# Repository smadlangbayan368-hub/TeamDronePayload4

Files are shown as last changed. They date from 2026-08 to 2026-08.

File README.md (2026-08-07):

# Team 4's Solution to Classroom Challenge Project <'Drone Payload Capacity and Structural Design Analysis Problem'>
This project challenges a team into applying core concepts of physics and engineering to the real-world problem of maximizing the payload capacity of a quadcopter. At the end of this project the team will have practiced designing drone arms and 3D modeling them, programing with MATLAB, and propose a final drone arm design through quantitative and cost analysis.  
  
Please refer to 'DroneDesign_StudentProjectTemplate_Preview.pdf' located in the Documentations folder and [Link](https://github.com/mathworks/MATLAB-Simulink-Challenge-Project-Hub/tree/main/Classroom%20Challenge%20Projects/Projects/Drone%20Payload%20Capacity%20and%20Structural%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) for more specifics about assumptions and requirements.

# Objective
Design at least 2 drone arms with the following criteria:
-  0.5 Kg payload at minimum
-  2:1 thrust-to-weight ratio (TWR) at minimum
-  Factor safety of at least 1.5

 Produce a final report from the results that were gathered for the drone arms  
  -  Including a final design recommendation with justification from analysis of results.   

Bonus Goal (Personal):
-  Design the drone arm such that it can carry a commercially available payload

# Project Details
## Assumptions 
-  Initial drone weight = 1Kg  
    -Composes the motors, propellors, electronics, main body, etc.) (Refer above for more details)  
-  Thrust to Weight Ratio = 2:1 (This value is locked to this to ensure maximization of payload weight)  
-  Factor of Safety >= 1.5 (Suggested by problem documentation. Also the standard)
-  Motor(65g) and propeller weight(10g) reduce total force at motor holes to 9.07N 

## Datasets  
-  'droneArmMaterials.mat' (Given in Repo and loads the data of materials that were specified in the problem)  
-  Drone arms (Given in repo.)  
    -'Circle_Arm.STL'   
    -'Triangle_ArmMOD.STL'  
    -'Beam_Arm.STL'  
    -'Lattice_ArmV2.STL'
-  'BackupData.Mat'(For the backup program and not needed to run the main one)
  
## Approach
Our team approached this project as a learning opportunity to better our skills with the suggested. So, each team member proposed and designed at least one drone arm. As a result of this we ended up with 4 comparable drone arms. Being the Triangle Arm, Circle Arm, Beam Arm, and Lattice Arm designed by each member. Afterwards we coded a MATLAB program using their built in Partial Differential Equation Toolbox. Allowing us to gather the results necessary to fulfill the project.

| Triangle Arm | Circle Arm |
| :---: | :---: |
| SLDWORKS_ej1l8cpXoL | chrome_BmiyGrPS0T |
| Beam Arm | Lattice Arm |
|  | SLDWORKS_YRguiKzV26 |

# Project Solution Instructions
**!Note: The Checks folder contains tools our team used tools for this project as documentation. They are not intended to work without tinkering on the user's end and are not required for the main program!**  

The following are steps on how to run the main program of this project being, "Full_Run_Fin.mlx".  
In the case that unexpected problems occur when following the Steps section and troubleshooting isn't fixing it. Please refer to the Backup Steps section to view the results. Otherwise Backup Steps can be skipped
## Steps:  
[Video Instructions](https://youtu.be/7ymWV30FWfM)
1. Download the repository/zip file (Click the Green button arrow drop down and hit download zip)
2. Right-click the zip and click extract all then, extract
3. A new window should open up. Click the folder in the window and double-click "Full_Run_Fin.mlx"
4. Click the run button and wait. (It takes about 4-5mins)
5. While waiting you should disable synchronous scrolling by right-clicking the right side and hitting "Disable synchronous scrolling" and scroll down to the bottom of both sides
6. After it has finished running you can view the results with the PDE results visualizer.

### Backup Steps
If you are reading this section then a problem has occurred with the "Full_Run_Fin.mlx" program. If this is not the case skip this section. Otherwise this section gives instructions on how to view the results with the data our team got from running this program.  
[Video Instructions](https://youtu.be/FH9hUVbYAe8)  
1. Download the following file (~84Mb) : [Link](https://drive.google.com/file/d/1TKJ5EevO7ercXoPHVxo5OthLvc5Kcq4C/view?usp=sharing)
2. Put the downloaded file into the Backup folder from the download. (or download the backup folder only and put the mat file in there).  
3. Open the backup program and run it.
4. You should now be able to view the results that our team got from running the "Full_Run_Fin.mlx" program.

# Results
Please download the repository and open the "Final Report.pdf" to view the report.

Note: The thrust to weight ratio (TWR) results are locked to 2 in order to maximize payload capacity. 
After running "Full_Run_Fin.mlx" and letting it finish. It will give the following result table:



# Reference
-[Introduction to Finite Element Analysis in MATLAB](https://matlabacademy.mathworks.com/details/introduction-to-finite-element-analysis-with-matlab/otmlfea)  
-[Example Finite Element Analysis Workflow](https://www.mathworks.com/help/pde/ug/deflection-analysis-of-bracket-femodel.html)  
-[Research Paper "Stress and vibration analysis of a drone"](https://iopscience.iop.org/article/10.1088/1757-899X/1009/1/012059/pdf)  
-[Real world Payload Data](https://www.jouav.com/blog/drone-payload.html)  

# Contact 
Email: rdnguyen.work@gmail.com

# Contributions
Ryan Nguyen
  -  Designed and modeled the Beam Arm
  -  Wrote "Full_Run_Fin.mlx" program
  -  Wrote "BackupProgram.mlx" program
  -  Writing report\
    -  Wrote section on beam arm and cost analysis\
    -  Graphs and research of payloads  
    -  Formatting  

Sheryl
  -  Designed and modeled Circular Arm
  -  Fine tuned FEA results\
    -  Wrote "TWR_and_MaxPayload.m" a program to gather FEA, TWR, and cost results
  -  Performed hand calculation checks for results\
    -  See "handCalculationExample.pdf" in Documentation
  -  Writing report\
    -  Wrote section on circular arm, goals and objectives, analysis, and conclusion\
    -  Provided pictures/documentation of Circular Arm  
    -  Formatting  

Ezekiel Savage
  -  Designed and modeled Triangle Arm
  -  Fine tuned FEA results\
    -  Wrote 'checkDroneArm.m' a program to perform quick FEAs  
    -  Perform sanity checks for FEA results  
   -  Writing report\
     -  Wrote section on Triangle Arm\
     -  Provided pictures/documentation of Triangular Arm  

Peter Yang
  -  Designed and modeled Lattice Arm  
  -  Performed hand calculation checks for results\
    -  See DorneTeam4_Hand_Calculations.pdf in Documentation folder
  -  Writing report\
    -  Wrote section on Lattice Arm\
    -  Provided pictures/documentation of Lattice Arm
  -  Wrote a program to perform FEA on Lattice Arm  
    -  Go to checks > Peter's Functions

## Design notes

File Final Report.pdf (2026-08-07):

# Drone Payload Capacity and Structural

# Design Analysis Team 4

# Report

# Team 4: Sheryl Madlangbayan, Ryan

# Nguyen, Peter Yang, Ezekiel Savage

### 1 Project Goals, Framing & Design Requirements

### 1.1 Project Goals and Objectives

- The primary objective of this project is to evaluate and optimize drone arm structural

performance subject to rigorous multi-physics and economic constraints:

- Geometric Concepts: Evaluate at least two distinct drone arm design sketches/CAD

concepts showing key structural features.

- Thrust-to-Weight Analysis: Analyze total system mass and thrust margins presented via

summary tables and performance metrics.

- Finite Element Analysis (FEA): Execute static structural solvers to extract multi-axis

displacements and peak von Mises stress distributions.

- Payload Versatility: Ensure compatibility with realistic modular commercial payloads,

specifically focusing on the DJI Zenmuse payload series:

- Zenmuse H20: 678±5 g
- Zenmuse H20T: 828±5 g
- Zenmuse S1: 760g±10 g

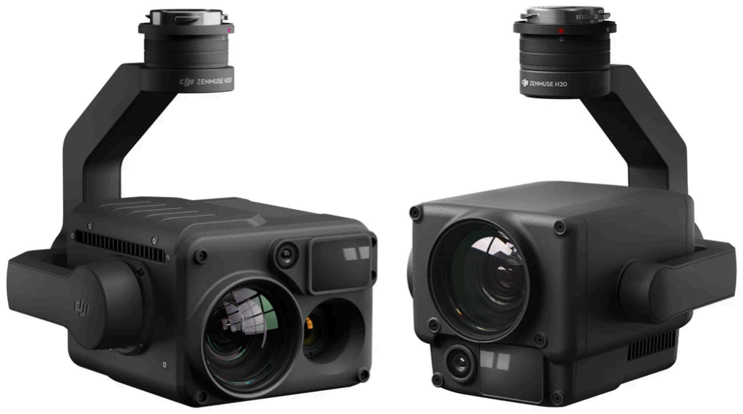
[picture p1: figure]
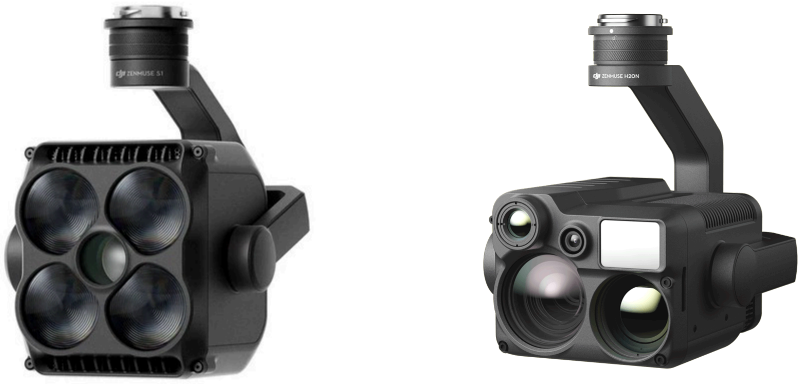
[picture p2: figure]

- Zenmuse H20N 878±5 g | H20T and H20 (Link) (https://enterprise.dji.com/zenmuse-h20-series/specs) | S1 (Link) (https://enterprise.dji.com/zenmuse-s1/specs) | H20N (Link) (https://enterprise.dji.com/zenmuse-h20n/specs)
- Strict Performance Thresholds:
- Allowable Tip Displacement (δmax): ≤ 1.0 mm
- Target Factor of Safety (FoS): 1.5 ≤ FoS ≤ 2.0 (Operational minimum FoS ≥ 1.5)
- Thrust to Weight Ratio (TWR): 2 (Locked at 2 to ensure max payload capacity)
- Tool Proficiency: Gain practical engineering competency in advanced analytical

modeling, CAD, and MATLAB PDE Toolboxes.

### 1.2 Problem Framing and Design Philosophy

The baseline drone platform comprises a fixed 1.0 kg core (flight controller, battery, body

frame, motors) and a total quadcopter thrust capacity of 39.24 N (9.81 N per motor). Two distinct

arm concepts were framed for comparison:

1. Sheryl’s Solid Plate / Uniform Cross-Section Arm: Prioritizes rapid modeling,

toughness along the primary bending axis, and simple flat-sheet manufacturing processes

(e.g., carbon fiber CNC routing, waterjet cutting, 3D printing).

2. Ryan’s, Ezekiel’s , and Peter’s Lattice Arms (Lattice Arm, Beam Arm, and

Trianglemod arm): Focuses on aggressive material removal using internal structural

trusses to reduce dead weight while preserving second moment of area (I).

### 2 Drone Arm Methodology

### 2.1 Triangle Arm (Zeke)

Flat Arm

The arm began with a simple shape

idea, a hexagonal mounting plate with a

straight rectangular arm with the width equal to

one side of the hexagonal mounting plate. On

the mounting plate, there are four holes meant

to be screw holes for the motor. On the other

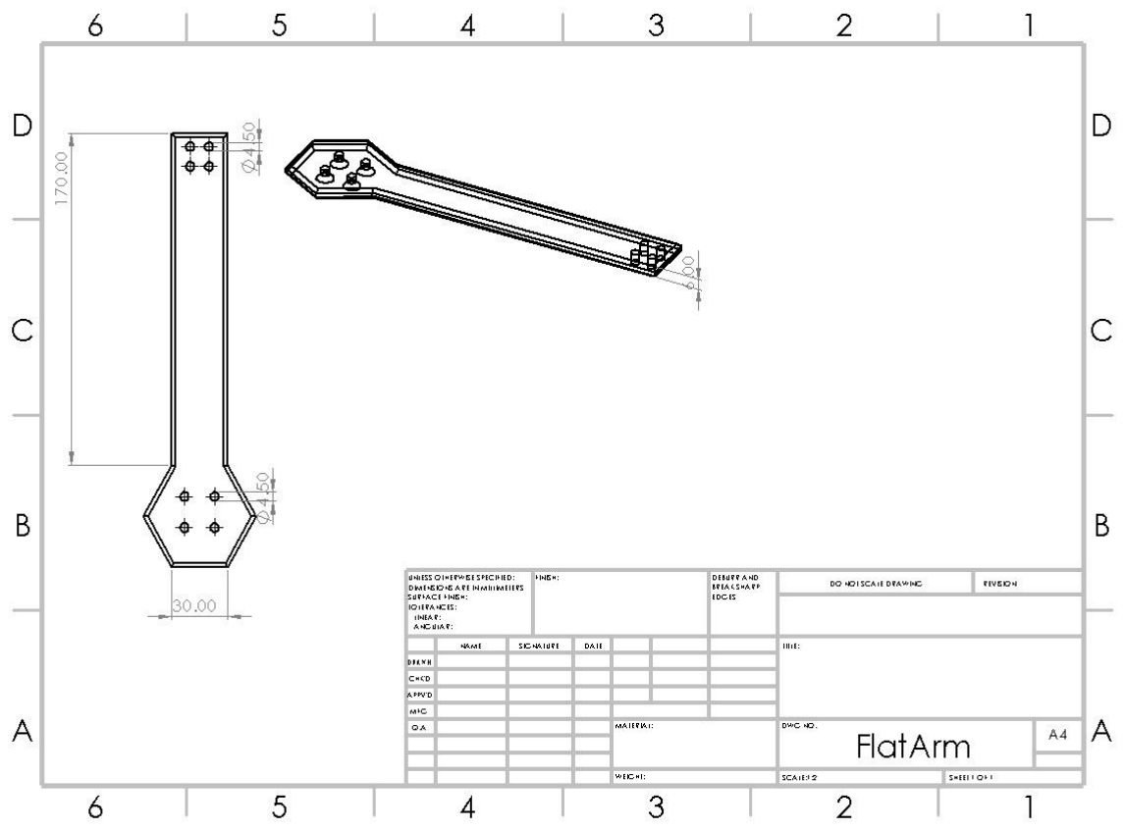
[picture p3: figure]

end, there are another four screw holes to attach to | (First Iteration)

the drone body. No dimension parameters had been set at the time of design and it was meant to

be a preliminary design. Still, some dimensions such as depth and the sides of the hexagon were

kept. The FEA of the first results showed a high safety factor, but it did not maximize payload

mass.

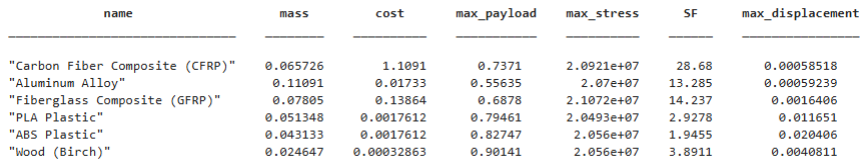
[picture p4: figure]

(First Iteration Results)

Triangle Arm

The first lattice iteration has a

trapezoidal mounting plate and a

rectangular body that is as wide as the

base of the trapezoidal mounting plate.

Triangular gaps are left in the body,

creating a truss-like structure with two

outer and one inner beams running along

the length of the arm with thinner beams

outlining the triangular gaps. On the

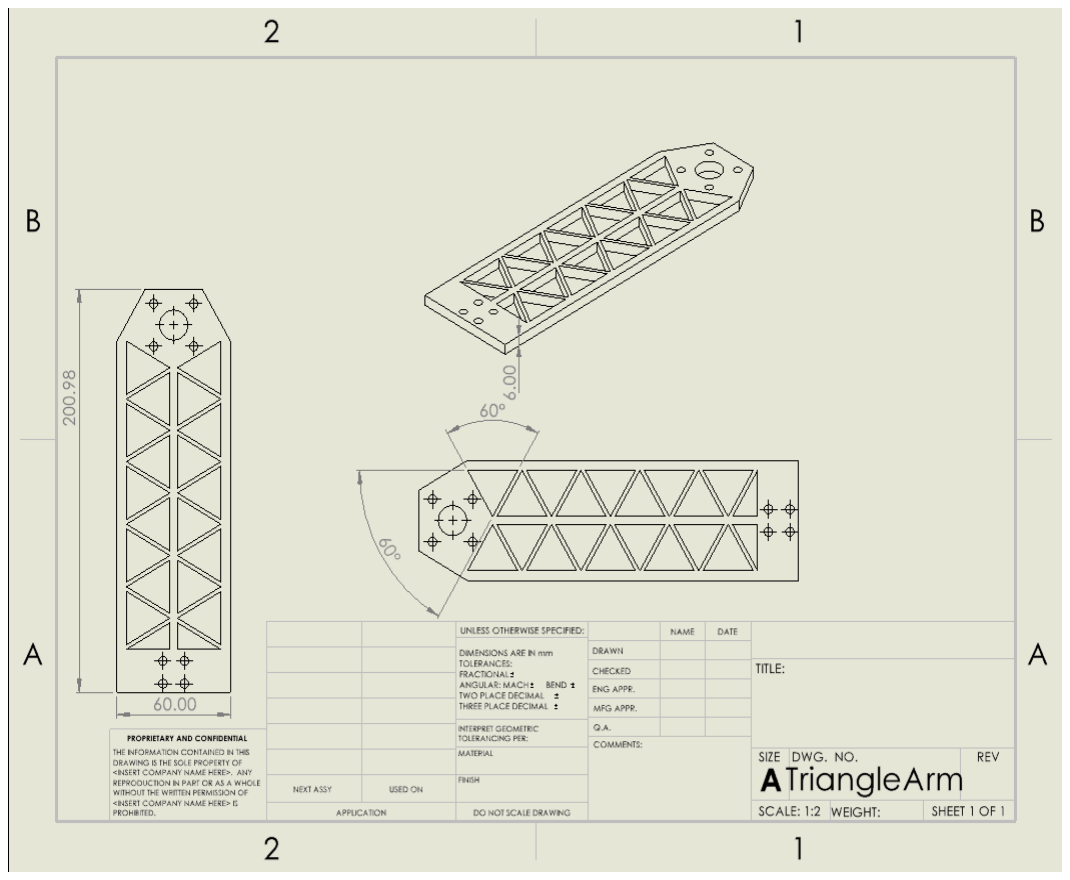
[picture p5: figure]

mounting plate, there are four screw | (Triangle Arm Drawing)

holes and a large central hole for the motor. On the other end, there are four screw holes. This

design was meant to minimize weight while keeping strength by strategically cutting material.

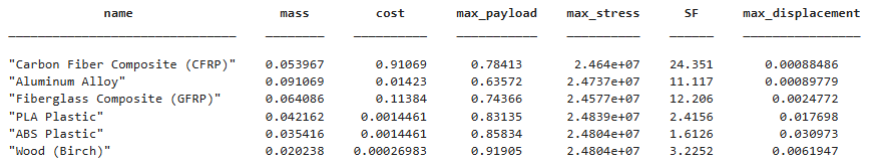
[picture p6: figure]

(Triangle Arm results)

The triangle arm’s FEA results showed a lower safety factor than the first iteration, but all

materials maintained acceptable safety factors. The decreased mass also meant increased max

payload, which is the aim of optimization.

Modified Triangle Arm

The modified triangle

arm keeps most of the first

triangle arm’s geometry. The

triangle arm went through FEA

in MATLAB. The areas with

very low stress were removed to

shave geometry and lower the

mass without jeopardizing

strength. Small changes were

made repeatedly and FEA was

run. This process was

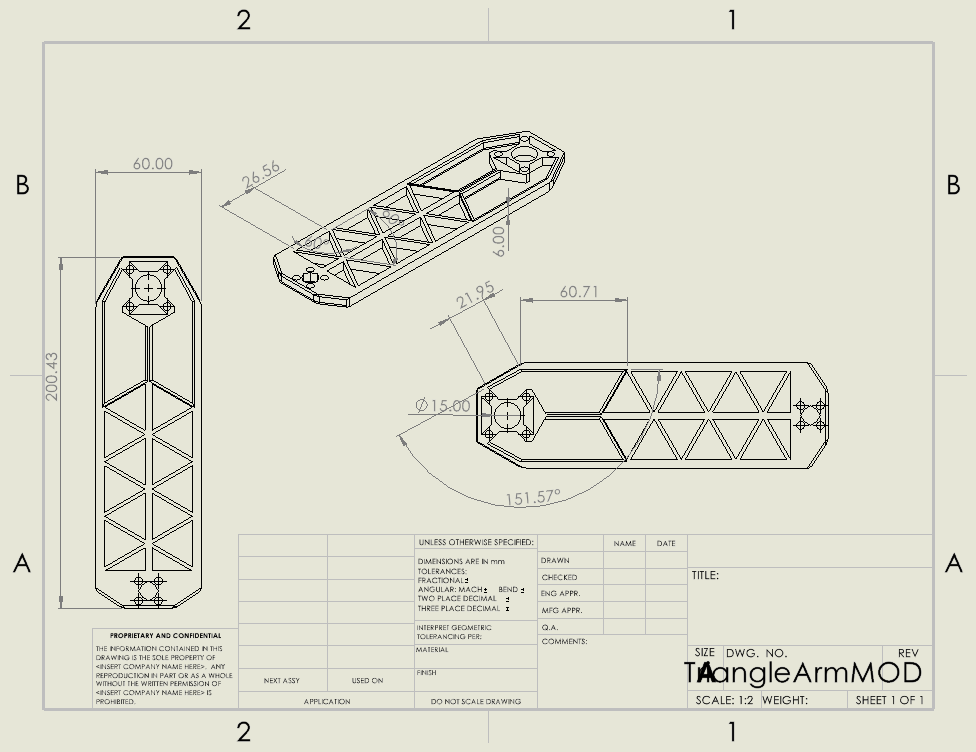
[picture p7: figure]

streamlined with a user-defined | (Modified Triangle Arm)

MATLAB function that could run FEA easily on the arm.

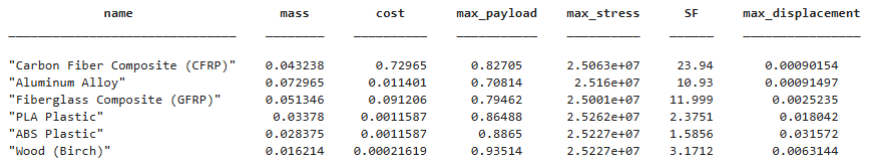
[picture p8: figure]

(Modified Triangle Arm results)

The modified triangle arm’s FEA results showed even lower, though still acceptable,

safety factors and greater max payloads. Though this design is far from perfect, it showcases

how a repeated, developed process can be used to optimize a design.

### 2.2 Circle Arm (Sheryl)

The smaller end acts as the frame pivot or mounting

joint, while the larger circular head serves as the motor mount

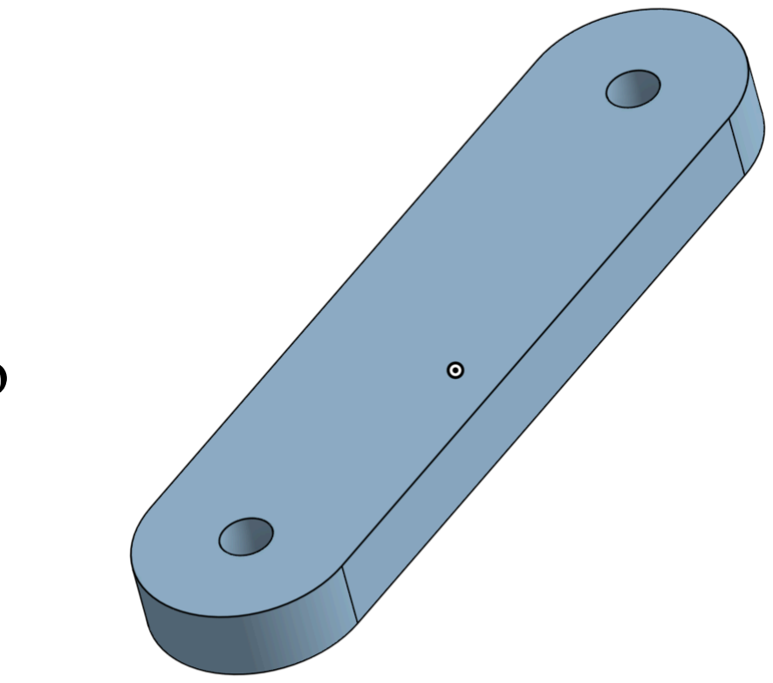
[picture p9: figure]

platform. Once the profile outline is established, it is extruded to

a uniform thickness to create the main solid body. Precise

cutouts are then added, including a single central through-hole

on the mounting end for a bolt or standoff, and a standard | (pic.1)

four-bolt pattern around a central clearance hole on the motor

end. To finalize the design, edge fillets are applied around the

perimeter to reduce stress concentrations and eliminate sharp

corners.

The first approach is the uniform solid plate design

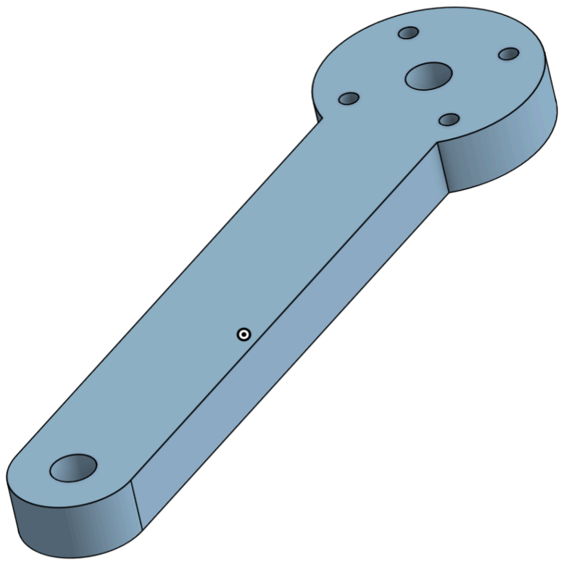
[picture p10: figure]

shown in the model. This philosophy prioritizes simplicity, | (pic.2)

rapid modeling, and seamless compatibility with flat-sheet manufacturing processes such as

carbon fiber CNC routing, waterjet cutting, or fast 3D printing. Solid plate arms offer exceptional

toughness along the primary bending axis, though the center beam retains extra dead weight

where solid mass is not strictly necessary for structural support.

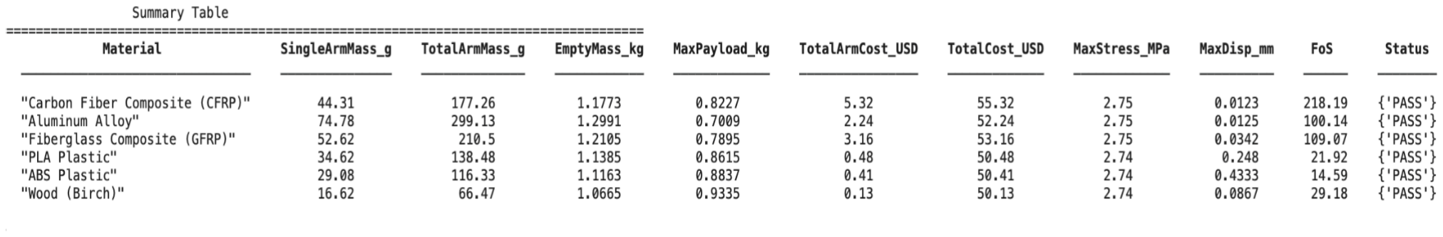
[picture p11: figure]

(Pic.3 Results Table)

It's definitely surprising to see Factors of Safety (FoS) in the double or triple digits at first

glance, but the math actually makes complete sense! An FoS doesn't need to be right around 1.0.

The main reason my numbers came out so high comes down to the relationship between the

applied load and the arm geometry. I set up the static load for a simple hover force of F=9.81 N

(about 1 kg of thrust), but applied it to a solid beam with a 20 mm×10 mm cross-section over a

short 90 mm span. A solid 20×10 mm section is actually huge for a force that small, which is

why the resulting maximum bending stress is only about 2.65 MPa. When you take typical

material yield strengths—like 275–600 MPa for Aluminum or Carbon Fiber—and divide them

by a tiny 2.65 MPa stress, the resulting FoS=σmaxσyield ratio naturally jumps well over 100. As

a result of that I changed the thickness from 10mm to 5mm yielding the following results.

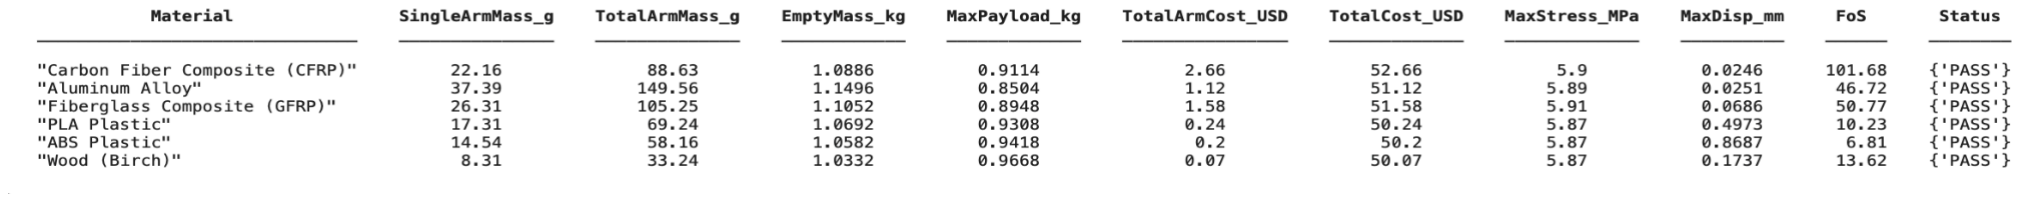
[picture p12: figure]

(Pic.3 Results Table for Final Revision)

### 2.3 Beam Arm (Ryan)

Start

This started off with a simple brainstorm

(fig.1) on potential designs for the drone arms.

Ranging from a curved structure to 2 arms acting

as one. At the end of this I decided to keep my

arm on the simpler side and went with a beam

drone arm with cutouts inspired by trusses.

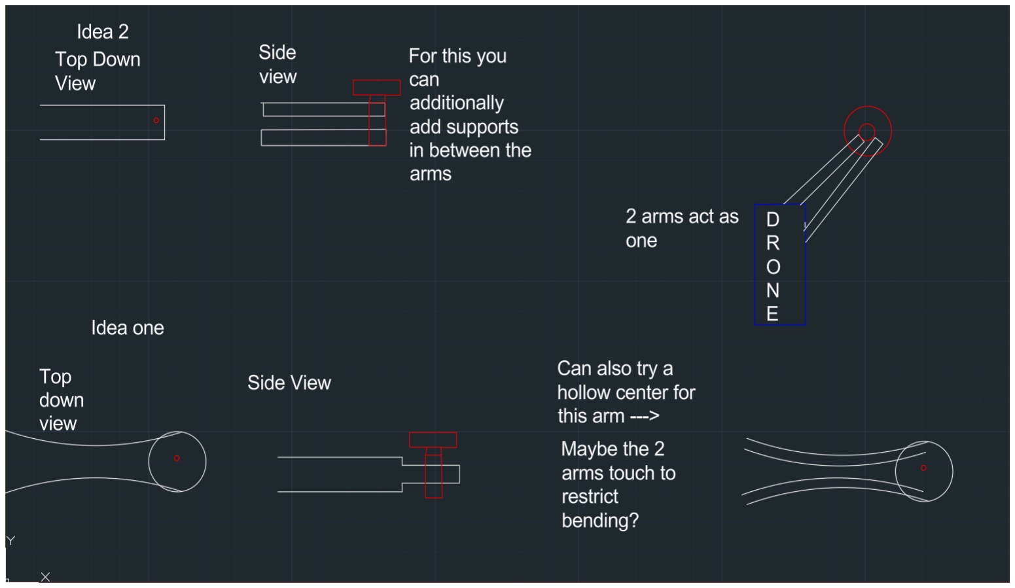
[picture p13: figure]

(fig.1)

1st Iteration

Which leads into one of the first drone arm

designs models made as seen in (fig.2). This design is

20x10x200mm and has alternating trapezoid cutouts to

better distribute the strength reduction from the cutouts.

Additionally to counter the thickness of the arm the

attachment side (left) has a cut out made with the

assumption that it would allow the drone body to slot in.

This design ended up daring well in the FEA results and

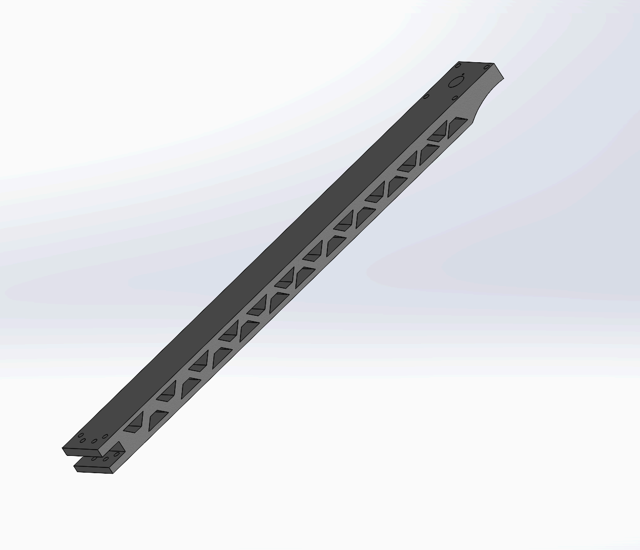
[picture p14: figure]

would have been a comparable arm for hitting the minimum | (fig.2)

targets of this project. However, it was a far cry away from hitting the goals that we set for

ourselves. As it would not be able to handle a majority of our desired payloads with the

exception of (CFRP). Thus, it was concluded that further improvements could be made to this

arm for better results.

Final Iteration

Leading to the final design of my

beam drone arm (fig.3). Thickness was

reduced to lower the weight of the arm

allowing for a heavier payload. Due to the

reduction the trapezoids weakened the arm

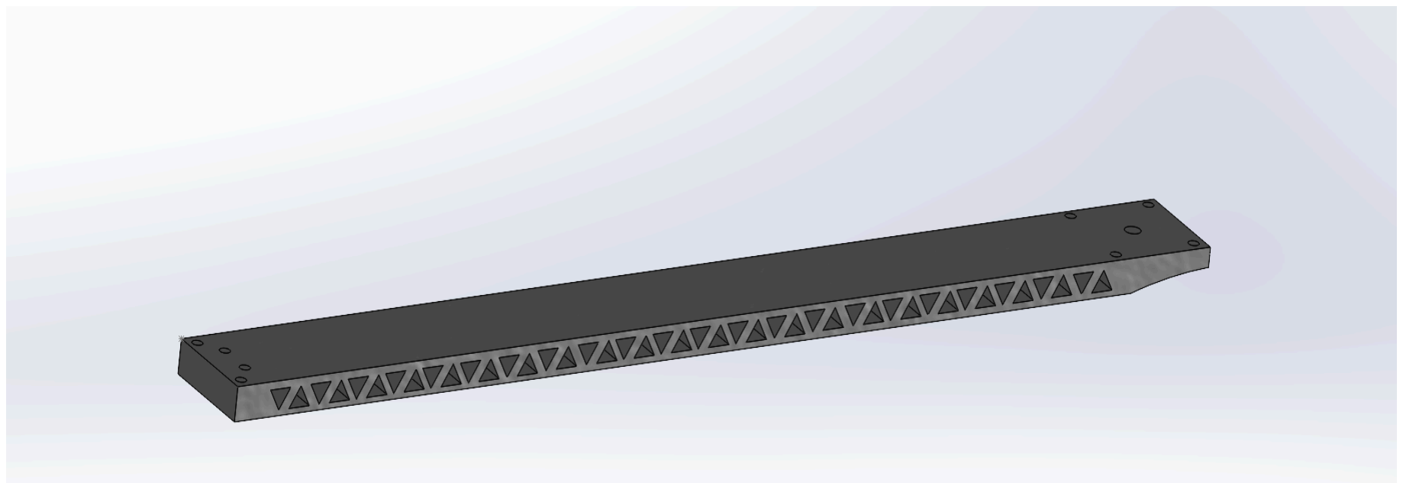
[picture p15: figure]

too much and caused the arm to fail the FEA. | (fig.3)
So, the cutouts were switched to triangles in | - 40% thickness reduction (10mm → 6mm)
order to maintain the arm’s strength. Lastly, | - Changed cutout shape
the cutout for the drone body was removed | - Removal of body cutout

due to the thickness being reduced. In addition this allows the arm to be more usable for more

drone bodies. As the body no longer needs to accommodate the cutout. This final design did well

in the FEA and allowed for most of the payloads in our goals section to be selectable.

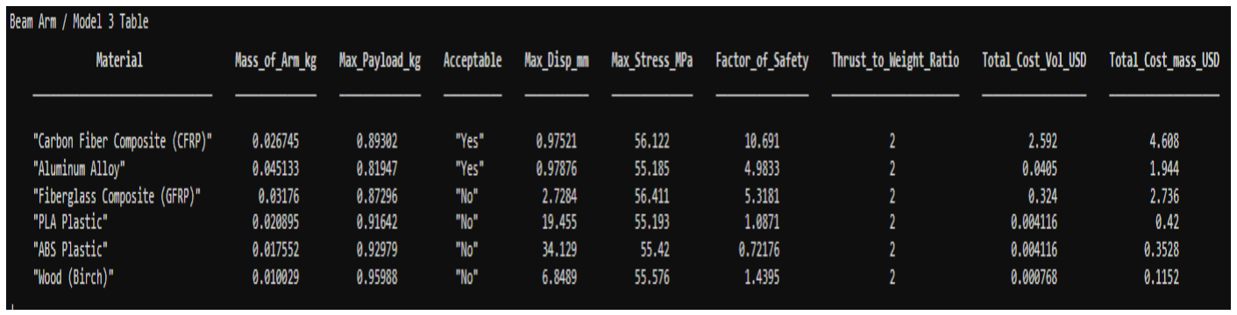
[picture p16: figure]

(Results Table of Final Iteration)

As seen the arm pushes the usable materials (material that passes the TWR, max Disp.,

and FoS checks) near their limits on acceptability for it. Allowing for a cost-effective arm while

staying within our regulations.

### 2.4 Lattice Arm (Peter)

Initial inspiration

With the primary goal of optimizing

thrust-to-weight ratio in mind, I started by

brainstorming ways to save weight on the

arm. My first idea was to hollow out the

middle section entirely, cutting material

wherever it wasn't strictly needed to hold the

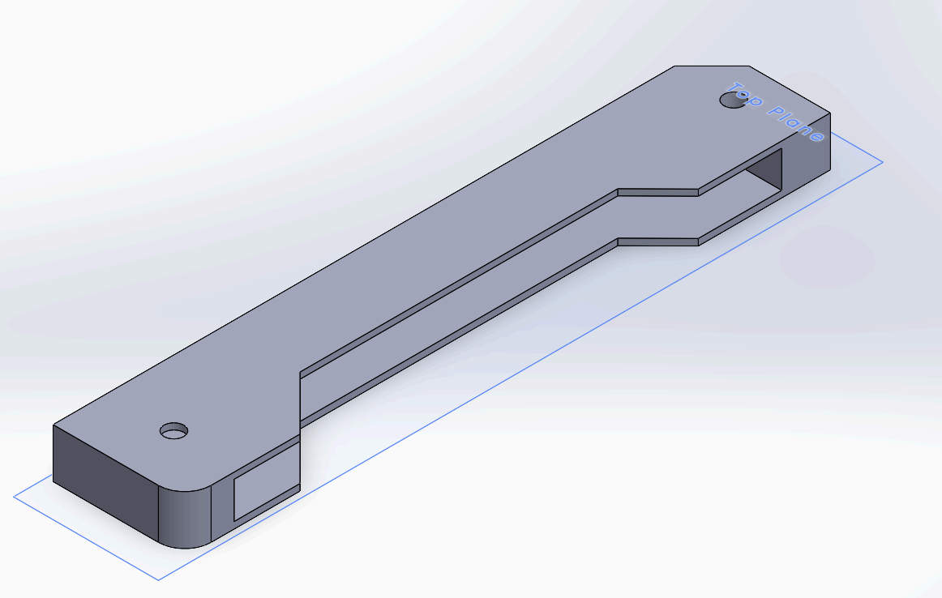
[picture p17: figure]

motor mount and body attachment points together. | (Initial design)

It was a simple approach as I just removed as much mass as possible without thinking too hard

about how that would affect the arm's ability to actually handle load.

Running this first version through the thrust-to-weight analysis showed the problem right

away: half the materials I was testing, including carbon fiber, aluminum, and fiberglass, actually

failed to meet the payload requirement outright, with aluminum coming in at a negative payload

value. Only the lighter, lower-stiffness materials like PLA, ABS, and wood managed to pass. The

FEA results made the tradeoff even clearer as those same passing materials had terrible factors of

safety, with ABS barely clearing 2.67 and PLA at 4.05, while displacement for PLA, ABS, and

wood ballooned into multiple millimeters. The hollow-out approach had saved weight, but it

gutted the arm's structural integrity so badly that it wasn't a viable design, even for the materials

that technically passed.

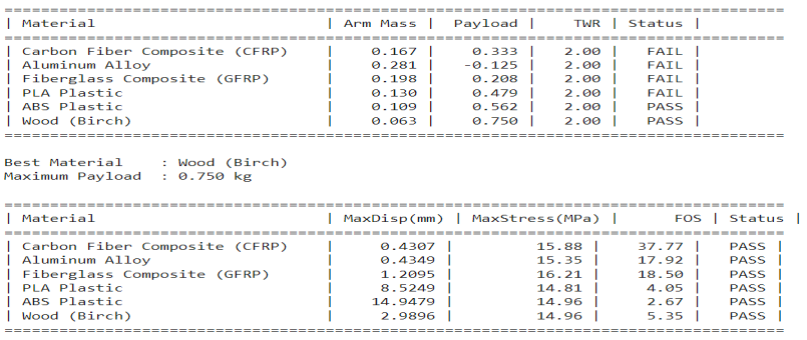
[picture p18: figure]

(Results Table of Initial Design)

Refined design inspiration

After some deeper research I

decided that instead of a completely hollow

midsection, I switched to a triangular lattice

pattern, which keeps most of the weight

savings of the hollow design while giving

the structure actual load paths to distribute

stress through. After discussing the design

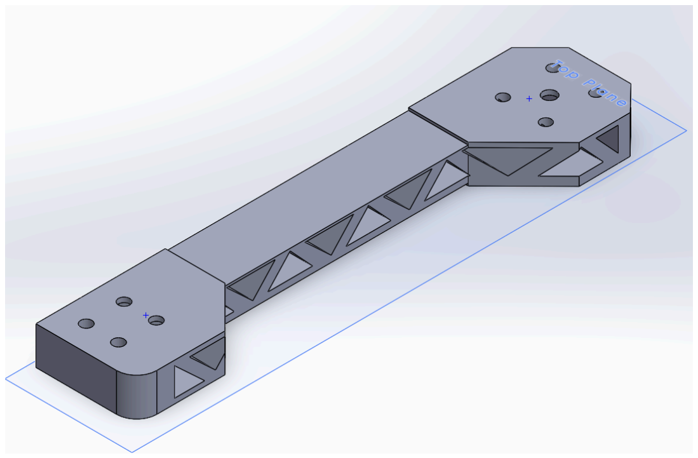
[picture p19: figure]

with the team, I also added more mounting | (Final Design)

holes for a more secure connection with four on the drone-body side and five on the payload

side. I cut small rectangular extrusions into the top and bottom faces as well, mainly so I could

clearly identify and select distinct faces when applying loads in the Matlab FEA. This wasn't

done for any structural or performance reason, just to make the analysis workflow more reliable.

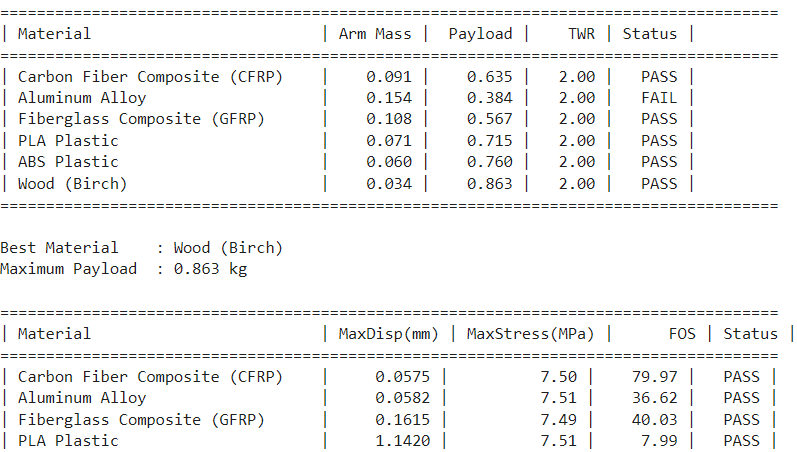
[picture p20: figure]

(Results Table of Final Design)

The redesign made a significant difference. In the updated thrust-to-weight results, every

material except aluminum alloy now passed the payload requirement, with wood coming out

highest at 0.863 kg. More importantly, the FEA results improved dramatically across the board

as carbon fiber's factor of safety jumped to nearly 80, and even the weaker performing materials

showed far more reasonable margins than in the initial design version. Displacement dropped

substantially too, staying well under a millimeter for the top-performing materials. Compared to

the original hollow design, the lattice pattern proved to be a much better balance between weight

savings and structural performance.

### Final Design Recommendation

We chose the circle arm design as our final drone arm because it successfully satisfies all

of the project requirements while providing a simple and robust structural design. The final

selection was based on the results of our thrust-to-weight analysis, payload analysis, and finite

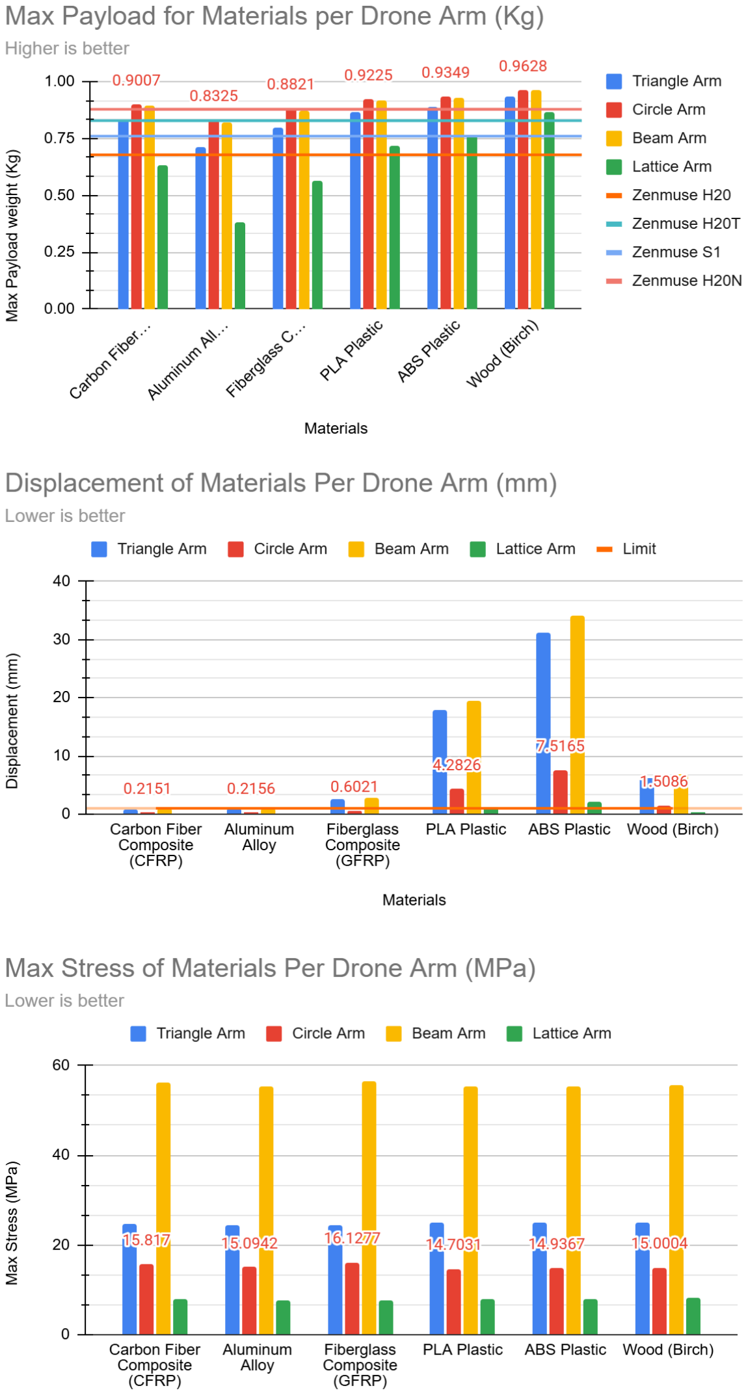
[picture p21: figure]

element analysis (FEA).

One of the primary requirements for

the drone arm was that it be capable of

carrying a minimum payload of 0.5 kg while

maintaining an allowable displacement of no

more than 1 mm and a factor of safety of 1.5+.

The circle arm exceeded these requirements

for half the materials considered in our

analysis. The FEA results showed that the

maximum displacement was significantly

below the 1 mm limit, indicating that the arm

experiences very little deformation under the

applied loading conditions with CFRP,

aluminum alloy, and GFRP. Similarly, the

calculated Von Mises stresses remained well

below the yield strengths of the materials,

resulting in factors of safety substantially

greater than the minimum requirement.

The thrust-to-weight and payload analysis also

demonstrated that the circle arm design maintained

sufficient lifting capability. Depending on the selected

material, the additional mass of the arm varied, but the

drone continued to have enough available thrust to

support the required payloads. This was particularly

important because the payloads considered in our

analysis, such as the DJI Zenmuse H20, H20T, S1, and

H20N, range from approximately 0.68 to 0.88 kg.

Therefore, designing only for the minimum 0.5 kg

payload would not have provided as much flexibility

for real-world applications.

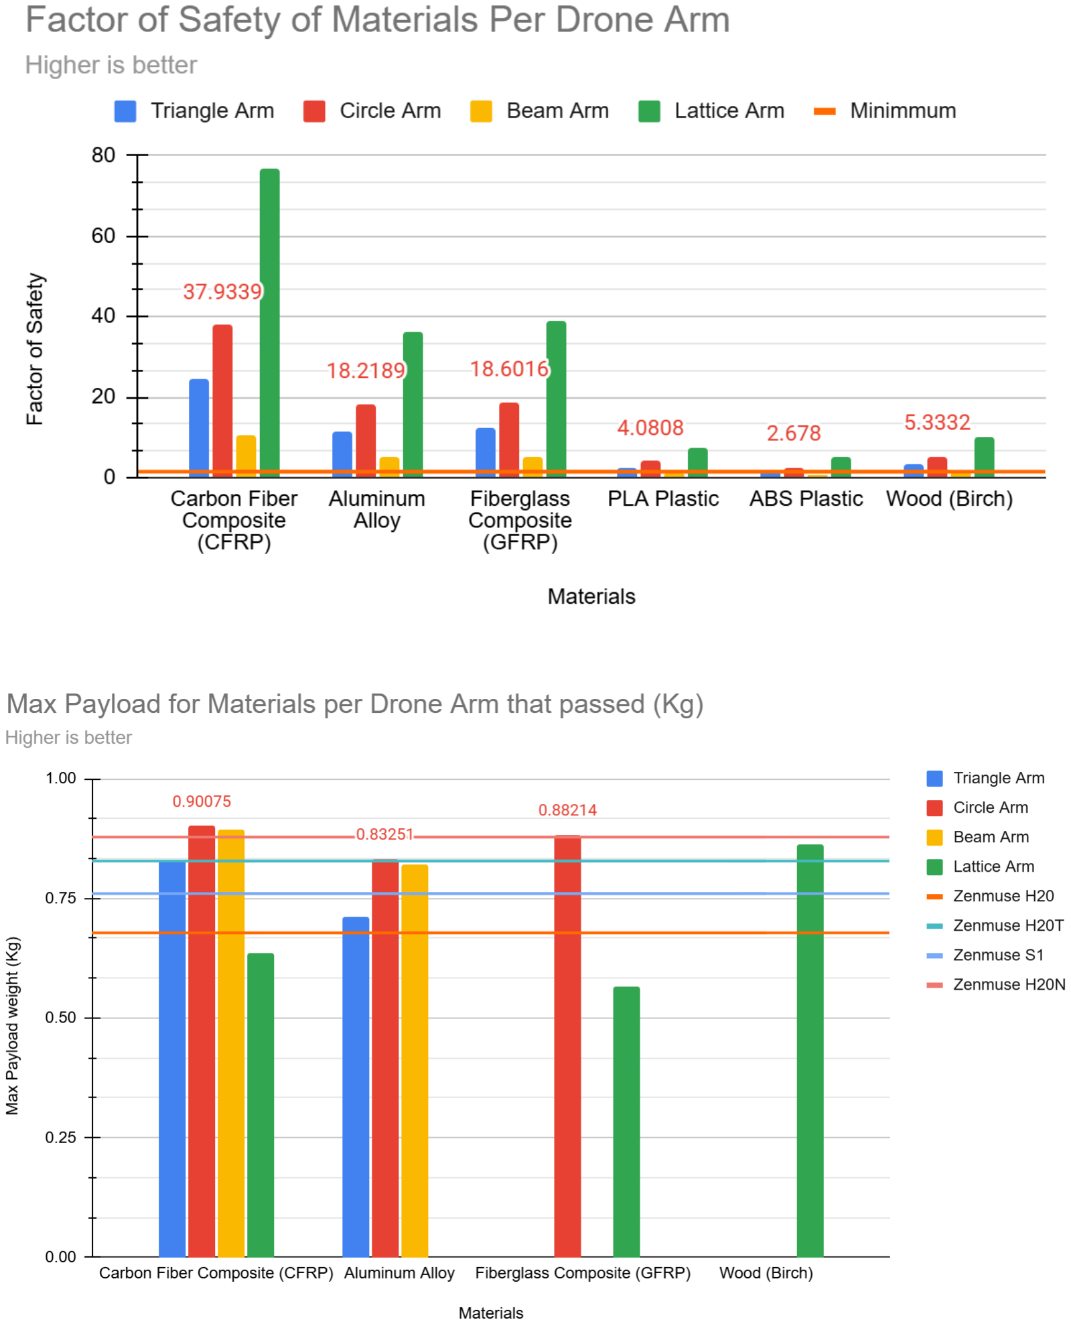
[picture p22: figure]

Another important consideration was the structural simplicity of the design. Compared

with a lattice-style arm, the circle arm has fewer complex geometric features and does not

require as much material to be strategically distributed throughout the structure. This makes the

design easier to manufacture, analyze, and modify. The continuous circle geometry also provides

a straightforward load path from the motor mounting region to the drone body, reducing the need

to account for stress concentrations associated with a more complex lattice structure.

The strength of the simplistic geometric structure is also reflected in its cost. As seen by

the graphs. It is one of the cheapest options to produce with high levels of performance

especially with max payload capacity. Allowing for a drone with this arm to be sent on missions

involving fires, aerial photography, search and rescue, and much more.

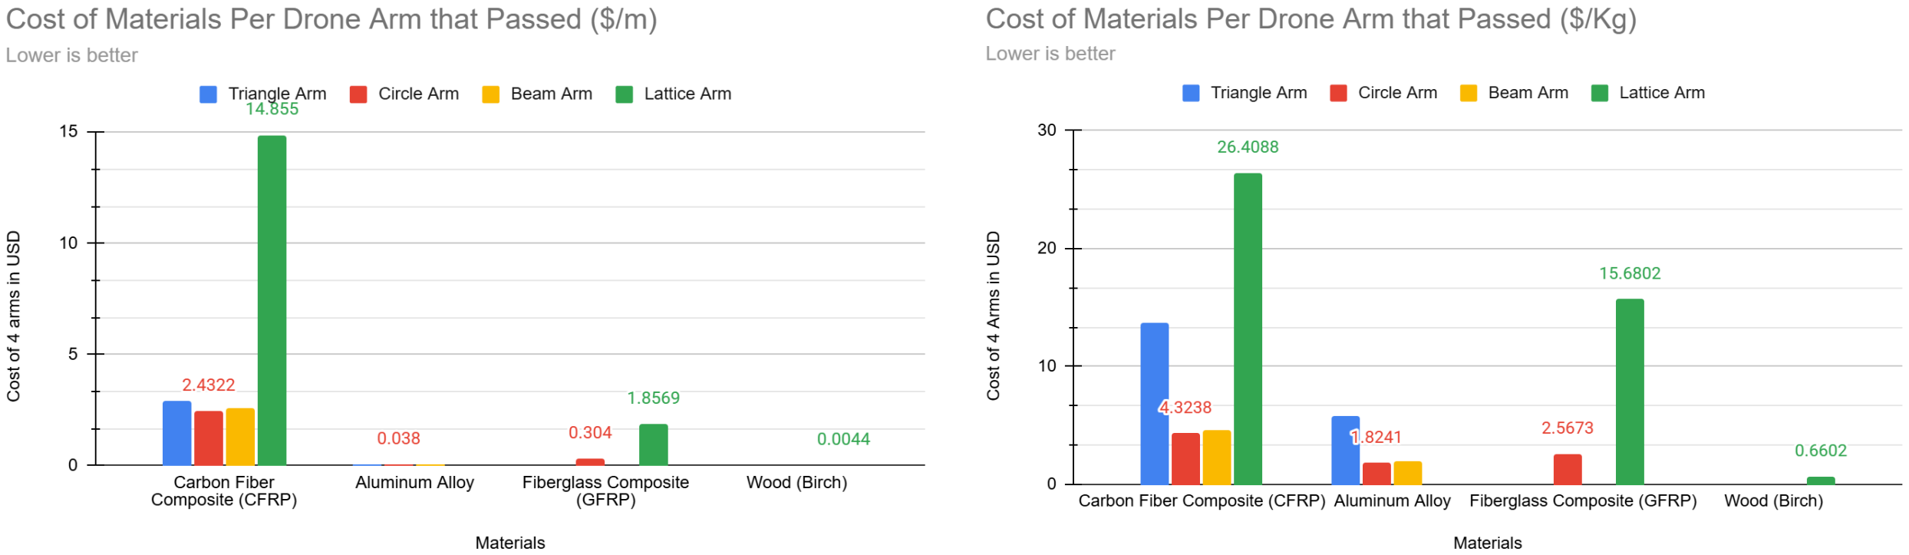
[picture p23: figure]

(Graphs give the material cost to make the drone arm using the uncut volume)

Ex. The beam arm is a 20x6x200mm drone arm. The material cost would thus be that of a 20x6x200mm block.

(Due to confusion with the cost for material in the data file we made 2 graphs.The left uses the given data as $/m and the right uses the same one, but as $/Kg.)

However, the results also revealed that the circle arm is more structurally conservative

than necessary. The extremely high factors of safety indicate that the design could potentially be

made lighter by removing material from areas that contribute less to structural performance. For

example, the carbon-fiber composite arm had a calculated factor of safety of approximately 218,

which is far above our target of 1.5+. While this provides a large margin against failure, it also

indicates that there is an opportunity for future optimization. Reducing unnecessary material

could decrease the arm's mass and consequently improve the drone's thrust-to-weight ratio and

available payload capacity.

Ultimately, we selected the circle arm because it provided a reliable and straightforward

solution that clearly satisfied the required performance criteria. Although a more optimized

lattice or topology-optimized design could potentially reduce mass, the circle arm offered greater

simplicity and a substantial structural margin while still meeting the payload, displacement, and

strength requirements. For the scope of this project, we determined that this balance of strength, payload capacity, manufacturability, and simplicity made the circle arm the most appropriate

final design.

### Final conclusion

The circle drone arm was selected because it met all required performance criteria and

provided a large margin of structural safety while maintaining sufficient payload capacity.

Although the design is conservative and could be further optimized for weight, its simplicity and

robust structural performance made it the most suitable design for the scope of this project.

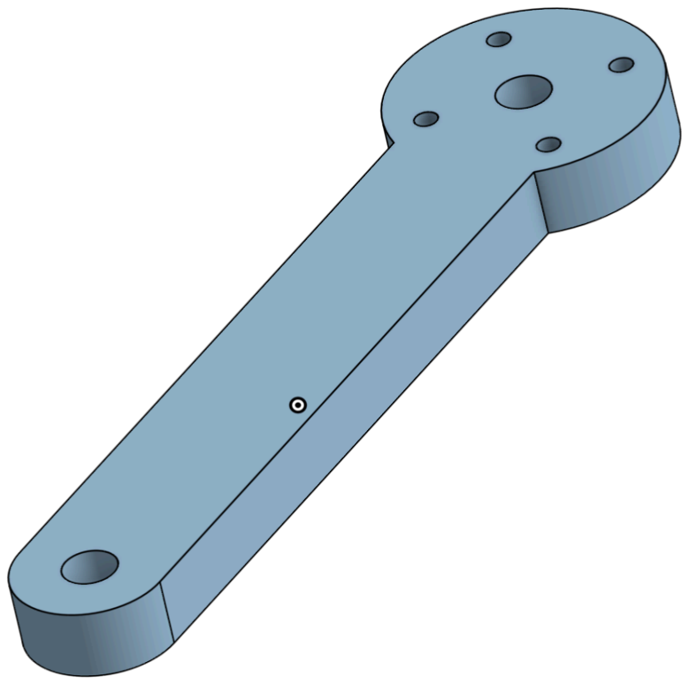
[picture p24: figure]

Final Choice: Circle Arm

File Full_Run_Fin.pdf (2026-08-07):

%Important to note that this program takes a fair amount of time to finish. %As 24 FEAs are being performed and 3 finer meshes are created.
%It takes about 2-5 mins to run

%Section 1 (Variable initialization) load("droneArmMaterials.mat")

%To get information from file do: materials(i).(TopRowName) %Ex. materials(1).name will give Carbon Fiber Composite (CFRP)
Max_mats = length(materials); %Used for amount of loop runs
MaxThrust = 4; %(kg)
DroneWeightAllowed = MaxThrust/2; %(kg) To ensure the 2:1 T/W ratio is followed MinPayLoad = 0.5; %(kg) Min req for payload
DroneComps = 1; %(kg) Weight of other drone components

%Variables to hold and display masses later
DroneArm1 = zeros(1,Max_mats)'; %(kg)
PayloadMax1 = zeros(1,Max_mats)'; %(kg)

DroneArm2 = zeros(1,Max_mats)'; %(kg) PayloadMax2 = zeros(1,Max_mats)'; %(kg)

DroneArm3 = zeros(1,Max_mats)'; %(kg) PayloadMax3 = zeros(1,Max_mats)'; %(kg)

DroneArm4 = zeros(1,Max_mats)'; %(kg)
PayloadMax4 = zeros(1,Max_mats)'; %(kg)

%Importing of models. Matlab always assumes ms when handling models. Scale %function is there to allow for proper FEA and calcs.
%models are in mm except 2

%For the best experience for importing models please use SolidWorks
gm1 = importGeometry("Triangle_ArmMod.STL");
gm2 = importGeometry("Circle_Arm.STL"); %model in m already
gm3 = importGeometry("Beam_Arm.STL");
gm4 = importGeometry("Lattice_ArmV2.STL");

gm1 = scale(gm1, 1E-3);
%scale(gm2, 1E-3);
gm3 = scale(gm3, 1E-3);
gm4 = scale(gm4, 1E-3);

md1 = femodel(AnalysisType="structuralStatic", Geometry = gm1); md2 = femodel(AnalysisType="structuralStatic", Geometry = gm2); md3 = femodel(AnalysisType="structuralStatic", Geometry = gm3);

md4 = femodel(AnalysisType="structuralStatic", Geometry = gm4);

%No longer needed. Can be accessed through mds
clearvars gm1 gm2 gm3 gm4

%model 2 required are coarser mesh
%model 3 required a finer one compared to the others. md1 = generateMesh(md1, Hmin=.0005, Hmax=1);
md2 = generateMesh(md2);
md3 = generateMesh(md3, Hmin=.00005, Hmax=1);
md4 = generateMesh(md4, Hmin=.0005, Hmax=1);

%Section 2 (For devs)

%This section is for other programmers adapting the code for their models. %These pde functions are here to allow you to quickly run this section to %see where the faces are for the model

%figure
%pdemesh(md1);
% %figure
%pdemesh(md2);
% %figure
% pdemesh(md3);
%
% pdemesh(md4);
%
%
% figure
% pdegplot(md1,FaceLabels="on", FaceAlpha=.3); % figure
% pdegplot(md1,FaceLabels="on", FaceAlpha=1); %
% figure
% pdegplot(md2,FaceLabels="on", FaceAlpha=0.3); % figure
% pdegplot(md2,FaceLabels="on", FaceAlpha=1); %
% figure
% pdegplot(md3,FaceLabels="on", FaceAlpha=0.3); % figure
% pdegplot(md3,FaceLabels="on", FaceAlpha=1); % figure
% pdegplot(md3,FaceLabels="off", FaceAlpha=1); %
% figure
% pdegplot(md4,FaceLabels="on", FaceAlpha=0.3); % figure
% pdegplot(md4,FaceLabels="on", FaceAlpha=1);

%

%Section 3 (Thrust to weight analysis occurs here)

names = strings(1,Max_mats)'; %Holds names of materials in a vector col for more convenient use later.

%Vol variables are created to calculate weights and costs of the drone arms %Vol#c is created with the assumption that the material will be cut from a %block of material. Thus using more actual material than the volume command %of the mesh states.
% The 2 separate cost variables are the result of the
%confusion in regards to how much materials costs. cost# assumes the %materials cost column is in ($/m) while cost#g assumes it to be ($/Kg)

%The vol#c calc assumes the models are aligned with the origin point and %take up space in the positive direction.
vol1=volume(md1.Geometry.Mesh);
vol1c =
max(md1.Geometry.Vertices(:,1))*max(md1.Geometry.Vertices(:,2))*max(md1.Geometry.Ver tices(:,3));
cost1 = zeros(1,Max_mats)';
cost1g = zeros(1,Max_mats)';

%Model 2 was made in a different program. So, it's vol2c was hand calculated. vol2=volume(md2.Geometry.Mesh);
vol2c = 2.252E-5;
cost2 = zeros(1,Max_mats)';
cost2g = zeros(1,Max_mats)';

vol3=volume(md3.Geometry.Mesh);
vol3c =
max(md3.Geometry.Vertices(:,1))*max(md3.Geometry.Vertices(:,2))*max(md3.Geometry.Ver tices(:,3));
cost3 = zeros(1,Max_mats)';
cost3g = zeros(1,Max_mats)';

vol4=volume(md4.Geometry.Mesh);
vol4c =
max(md4.Geometry.Vertices(:,1))*max(md4.Geometry.Vertices(:,2))*max(md4.Geometry.Ver tices(:,3));
cost4 = zeros(1,Max_mats)';
cost4g = zeros(1,Max_mats)';

%Calc for drone arm weights, max payload, and costs
%This is also where the Thrust to Weight ratio (TWR) analysis occurs. %Since the TWR is locked at 2 from the variable setup in section 1 to

%ensure the heaviest payload possible.

for i = 1:Max_mats
names(i) = materials(i).name;
DroneArm1(i) = vol1 * materials(i).rho_kg_m3;
PayloadMax1(i) = DroneWeightAllowed - DroneArm1(i)*4 - DroneComps; %This calc ensures a 2:1 TWR
cost1(i) = vol1 * (materials(i).cost_USD_per_m^3);
cost1g(i) = vol1c * materials(i).rho_kg_m3 * materials(i).cost_USD_per_m;

DroneArm2(i) = vol2 * materials(i).rho_kg_m3;
PayloadMax2(i) = DroneWeightAllowed - DroneArm2(i)*4 - DroneComps; cost2(i) = vol2c * (materials(i).cost_USD_per_m)^3;
cost2g(i) = vol2c * materials(i).rho_kg_m3* materials(i).cost_USD_per_m;

DroneArm3(i) = vol3 * materials(i).rho_kg_m3;
PayloadMax3(i) = DroneWeightAllowed - DroneArm3(i)*4 - DroneComps; cost3(i) = vol3c * (materials(i).cost_USD_per_m)^3;
cost3g(i) = vol3c * materials(i).rho_kg_m3* materials(i).cost_USD_per_m;

DroneArm4(i) = vol4 * materials(i).rho_kg_m3;
PayloadMax4(i) = DroneWeightAllowed - DroneArm4(i)*4 - DroneComps; cost4(i) = vol4c * (materials(i).cost_USD_per_m^3);
cost4g(i) = vol4c * materials(i).rho_kg_m3* materials(i).cost_USD_per_m;

end

%Section 4 (Applying locking faces and loading forces)

%This section is where the restraints and loads are placed on the model %Viewing the models will show that some of the models are orientated %differently. Which is why the loads are either applied on the y or z axis

%9.07 is the force that area of the arm faces.
% 9.8 - (9.8 * motor weight(65g)* propeller weight(10g)) = 9.065N
%It was then rounded up to 9.07N.
%It is then divided by the surface area of the face it is attached to (2*pi*r*depth) %Which makes the results give an approximation for FEAs
%Lastly sanity checks were done hand calced and using SolidWorks as a
%reference for results.

md1.FaceBC([63,64,65,66]) = faceBC(Constraint="fixed");
md1.FaceLoad(58) = faceLoad(SurfaceTraction= [0;0;9.07/(2*pi*7.5*6*1e-6)]); md1.CellLoad = cellLoad(Gravity=[0 0 -9.8]);

md2.FaceBC([12]) = faceBC(Constraint="fixed");
md2.FaceLoad(11) = faceLoad(SurfaceTraction= [0; 9.07/(2*pi*3.5*5*1e-6); 0]);

md2.CellLoad = cellLoad(Gravity=[0, -9.8, 0]);

md3.FaceBC([12,13,14,15]) = faceBC(Constraint="fixed");
md3.FaceLoad(11) = faceLoad(SurfaceTraction= [0;0;9.07/(2*pi*1.5*4.8*1e-6)]); md3.CellLoad = cellLoad(Gravity=[0 0 -9.8]);

md4.FaceBC([3,24,25,34]) = faceBC(Constraint="fixed");
md4.FaceLoad(26) = faceLoad(SurfaceTraction= [0;9.07/(2*pi*2.65*1.9*1e-6);0]); md4.CellLoad = cellLoad(Gravity=[0 -9.8 0]);

%Section 5 (FEA calcs)

%Pass this point are 4 big sections of code where FEA is performed on the 4 %drone arms. They are handled via switch case. Separate variables are used %to store the FEA results in order for the built in "Visualize PDE Results" %to allow the results to be selectable and viewable.

%Explanation comments return after this section

%Model 1
Max_Stress1 = zeros(1,6)';
Max_Disp1 = zeros(1,6)';
FoS1 = zeros(1,6)';
for i = 1:Max_mats

md1.MaterialProperties = ... materialProperties(YoungsModulus=materials(i).E_Pa, ... PoissonsRatio=materials(i).nu, ... MassDensity=materials(i).rho_kg_m3);

switch i
case 1
Model_1_result_CFRP = solve(md1);
Max_Stress1(i) = max(Model_1_result_CFRP.VonMisesStress); Max_Disp1(i) = max(Model_1_result_CFRP.Displacement.Magnitude); FoS1(i) = materials(i).yieldStrength_Pa / Max_Stress1(i); case 2
Model_1_result_Al_Alloy = solve(md1);
Max_Stress1(i) = max(Model_1_result_Al_Alloy.VonMisesStress); Max_Disp1(i) = max(Model_1_result_Al_Alloy.Displacement.Magnitude); FoS1(i) = materials(i).yieldStrength_Pa / Max_Stress1(i);
case 3
Model_1_result_GFRP = solve(md1);
Max_Stress1(i) = max( Model_1_result_GFRP.VonMisesStress); Max_Disp1(i) = max( Model_1_result_GFRP.Displacement.Magnitude); FoS1(i) = materials(i).yieldStrength_Pa / Max_Stress1(i);
case 4
Model_1_result_PLA = solve(md1);
Max_Stress1(i) = max(Model_1_result_PLA.VonMisesStress);

Max_Disp1(i) = max(Model_1_result_PLA.Displacement.Magnitude); FoS1(i) = materials(i).yieldStrength_Pa / Max_Stress1(i); case 5
Model_1_result_ASB = solve(md1);
Max_Stress1(i) = max(Model_1_result_ASB.VonMisesStress); Max_Disp1(i) = max(Model_1_result_ASB.Displacement.Magnitude); FoS1(i) = materials(i).yieldStrength_Pa / Max_Stress1(i); case 6
Model_1_result_Wood = solve(md1);
Max_Stress1(i) = max(Model_1_result_Wood.VonMisesStress); Max_Disp1(i) = max(Model_1_result_Wood.Displacement.Magnitude); FoS1(i) = materials(i).yieldStrength_Pa / Max_Stress1(i);

end

end

%For model 2
Max_Stress2 = zeros(1,6)'; Max_Disp2 = zeros(1,6)';
FoS2 = zeros(1,6)';
for i = 1:Max_mats

md2.MaterialProperties = ... materialProperties(YoungsModulus=materials(i).E_Pa, ... PoissonsRatio=materials(i).nu, ... MassDensity=materials(i).rho_kg_m3);

switch i
case 1
Model_2_result_CFRP = solve(md2);
Max_Stress2(i) = max(Model_2_result_CFRP.VonMisesStress); Max_Disp2(i) = max(Model_2_result_CFRP.Displacement.Magnitude); FoS2(i) = materials(i).yieldStrength_Pa / Max_Stress2(i); case 2
Model_2_result_Al_Alloy = solve(md2);
Max_Stress2(i) = max(Model_2_result_Al_Alloy.VonMisesStress); Max_Disp2(i) = max(Model_2_result_Al_Alloy.Displacement.Magnitude); FoS2(i) = materials(i).yieldStrength_Pa / Max_Stress2(i);
case 3
Model_2_result_GFRP = solve(md2);
Max_Stress2(i) = max( Model_2_result_GFRP.VonMisesStress); Max_Disp2(i) = max( Model_2_result_GFRP.Displacement.Magnitude); FoS2(i) = materials(i).yieldStrength_Pa / Max_Stress2(i);
case 4
Model_2_result_PLA = solve(md2);

Max_Stress2(i) = max(Model_2_result_PLA.VonMisesStress); Max_Disp2(i) = max(Model_2_result_PLA.Displacement.Magnitude); FoS2(i) = materials(i).yieldStrength_Pa / Max_Stress2(i); case 5
Model_2_result_ASB = solve(md2);
Max_Stress2(i) = max(Model_2_result_ASB.VonMisesStress); Max_Disp2(i) = max(Model_2_result_ASB.Displacement.Magnitude); FoS2(i) = materials(i).yieldStrength_Pa / Max_Stress2(i); case 6
Model_2_result_Wood = solve(md2);
Max_Stress2(i) = max(Model_2_result_Wood.VonMisesStress); Max_Disp2(i) = max(Model_2_result_Wood.Displacement.Magnitude); FoS2(i) = materials(i).yieldStrength_Pa / Max_Stress2(i);

end

end

%For model 3

Max_Stress3 = zeros(1,6)'; Max_Disp3 = zeros(1,6)';
FoS3 = zeros(1,6)';
for i = 1:Max_mats

md3.MaterialProperties = ... materialProperties(YoungsModulus=materials(i).E_Pa, ... PoissonsRatio=materials(i).nu, ... MassDensity=materials(i).rho_kg_m3);

switch i
case 1
Model_3_result_CFRP = solve(md3);
Max_Stress3(i) = max(Model_3_result_CFRP.VonMisesStress); Max_Disp3(i) = max(Model_3_result_CFRP.Displacement.Magnitude); FoS3(i) = materials(i).yieldStrength_Pa / Max_Stress3(i); case 2
Model_3_result_Al_Alloy = solve(md3);
Max_Stress3(i) = max(Model_3_result_Al_Alloy.VonMisesStress); Max_Disp3(i) = max(Model_3_result_Al_Alloy.Displacement.Magnitude); FoS3(i) = materials(i).yieldStrength_Pa / Max_Stress3(i);
case 3
Model_3_result_GFRP = solve(md3);
Max_Stress3(i) = max( Model_3_result_GFRP.VonMisesStress); Max_Disp3(i) = max( Model_3_result_GFRP.Displacement.Magnitude); FoS3(i) = materials(i).yieldStrength_Pa / Max_Stress3(i);
case 4
Model_3_result_PLA = solve(md3);

Max_Stress3(i) = max(Model_3_result_PLA.VonMisesStress); Max_Disp3(i) = max(Model_3_result_PLA.Displacement.Magnitude); FoS3(i) = materials(i).yieldStrength_Pa / Max_Stress3(i); case 5
Model_3_result_ASB = solve(md3);
Max_Stress3(i) = max(Model_3_result_ASB.VonMisesStress); Max_Disp3(i) = max(Model_3_result_ASB.Displacement.Magnitude); FoS3(i) = materials(i).yieldStrength_Pa / Max_Stress3(i); case 6
Model_3_result_Wood = solve(md3);
Max_Stress3(i) = max(Model_3_result_Wood.VonMisesStress); Max_Disp3(i) = max(Model_3_result_Wood.Displacement.Magnitude); FoS3(i) = materials(i).yieldStrength_Pa / Max_Stress3(i);

end

end

%For model 4
Max_Stress4 = zeros(1,6)'; Max_Disp4 = zeros(1,6)';
FoS4 = zeros(1,6)';
for i = 1:Max_mats

md4.MaterialProperties = ... materialProperties(YoungsModulus=materials(i).E_Pa, ... PoissonsRatio=materials(i).nu, ... MassDensity=materials(i).rho_kg_m3);

switch i
case 1
Model_4_result_CFRP = solve(md4);
Max_Stress4(i) = max(Model_4_result_CFRP.VonMisesStress); Max_Disp4(i) = max(Model_4_result_CFRP.Displacement.Magnitude); FoS4(i) = materials(i).yieldStrength_Pa / Max_Stress4(i); case 2
Model_4_result_Al_Alloy = solve(md4);
Max_Stress4(i) = max(Model_4_result_Al_Alloy.VonMisesStress); Max_Disp4(i) = max(Model_4_result_Al_Alloy.Displacement.Magnitude); FoS4(i) = materials(i).yieldStrength_Pa / Max_Stress4(i);
case 3
Model_4_result_GFRP = solve(md4);
Max_Stress4(i) = max( Model_4_result_GFRP.VonMisesStress); Max_Disp4(i) = max( Model_4_result_GFRP.Displacement.Magnitude); FoS4(i) = materials(i).yieldStrength_Pa / Max_Stress4(i);
case 4

Model_4_result_PLA = solve(md4);
Max_Stress4(i) = max(Model_4_result_PLA.VonMisesStress); Max_Disp4(i) = max(Model_4_result_PLA.Displacement.Magnitude); FoS4(i) = materials(i).yieldStrength_Pa / Max_Stress4(i); case 5
Model_4_result_ASB = solve(md4);
Max_Stress4(i) = max(Model_4_result_ASB.VonMisesStress); Max_Disp4(i) = max(Model_4_result_ASB.Displacement.Magnitude); FoS4(i) = materials(i).yieldStrength_Pa / Max_Stress4(i); case 6
Model_4_result_Wood = solve(md4);
Max_Stress4(i) = max(Model_4_result_Wood.VonMisesStress); Max_Disp4(i) = max(Model_4_result_Wood.Displacement.Magnitude); FoS4(i) = materials(i).yieldStrength_Pa / Max_Stress4(i);

end

end

%Section 6 (Checks for arm viability)

Useable1 = strings(1,Max_mats)'; Useable2 = strings(1,Max_mats)';
Useable3 = strings(1,Max_mats)';
Useable4 = strings(1,Max_mats)';

%Performs a check and stores it in a variable to display later. Allowing %for a quick check way to ensure that the arm fits the criteria in regards to %Factor of safety (FoS), can handle a 0.5Kg payload, and a Displacement of %less than 1mm
for i=1:Max_mats
if PayloadMax1(i) >= MinPayLoad && FoS1(i) >= 1.5 && Max_Disp1(i) <= 0.001 Useable1(i) = 'Yes';
else
Useable1(i) = 'No';
end
if PayloadMax2(i) >= MinPayLoad && FoS2(i) >= 1.5 && Max_Disp2(i) <= 0.001 Useable2(i) = 'Yes';
else
Useable2(i) = 'No';
end

if PayloadMax3(i) >= MinPayLoad && FoS3(i) >= 1.5 && Max_Disp3(i) <= 0.001 Useable3(i) = 'Yes';
else
Useable3(i) = 'No';
end if PayloadMax4(i) >= MinPayLoad && FoS4(i) >= 1.5 && Max_Disp4(i) <= 0.001 Useable4(i) = 'Yes';
else
Useable4(i) = 'No';
end
end

%Section 7 (Create the tables to be displayed)

%Creates tables to display the results
%The table is done this way to allow for
%quicker table modifications.

%All tables follow the same structure so, refer to Show1 for what each %column means.

TWR = [2;2;2;2;2;2]; %The program assumes maximization of payload weight. % So, thrust to weight ratio (TWR) will always be a 2:1 ratio.

Show1 = table();
Show1.Material = names; %Display the material of what the arm is made of Show1.Mass_of_Arm_kg=DroneArm1; %Displays the weight of one drone arm with the given material
Show1.Max_Payload_kg = PayloadMax1; %Displays the max payload capacity with the given material for the arm
Show1.Acceptable = Useable1; %Displays whether the arm meets the minimum requirements with the given material
Show1.Max_Disp_mm = Max_Disp1*1E3; %Max displacement of the arm with the given material
Show1.Max_Stress_MPa = Max_Stress1*1E-6; %Max stress of the arm with the given material
Show1.Factor_of_Safety = FoS1; %Factor of safety of the arm with the given material Show1.Thrust_to_Weight_Ratio = TWR; %Makes a column for the table to display TWR "Results"
%Show1.Cost = cost1;
Show1.Total_Cost_Vol_USD = cost1*4; %Cost of 4 arms with the given material using ($/m)
Show1.Total_Cost_mass_USD = cost1g*4; %Cost of 4 arms with the given material using ($/Kg)

Show2 = table();
Show2.Material = names;
Show2.Mass_of_Arm_kg=DroneArm2; Show2.Max_Payload_kg = PayloadMax2; Show2.Acceptable = Useable2; Show2.Max_Disp_mm = Max_Disp2*1E3; Show2.Max_Stress_MPa = Max_Stress2*1E-6; Show2.Factor_of_Safety = FoS2; Show2.Thrust_to_Weight_Ratio = TWR;

%Show2.Cost = cost2;
Show2.Total_Cost_Vol_USD = cost2*4; Show2.Total_Cost_mass_USD = cost2g*4;

Show3 = table();
Show3.Material = names;
Show3.Mass_of_Arm_kg=DroneArm3; Show3.Max_Payload_kg = PayloadMax3; Show3.Acceptable = Useable3; Show3.Max_Disp_mm = Max_Disp3*1E3; Show3.Max_Stress_MPa = Max_Stress3*1E-6; Show3.Factor_of_Safety = FoS3; Show3.Thrust_to_Weight_Ratio = TWR; %Show3.Cost = cost3;
Show3.Total_Cost_Vol_USD = cost3*4; Show3.Total_Cost_mass_USD = cost3g*4;

Show4 = table();
Show4.Material = names;
Show4.Mass_of_Arm_kg=DroneArm4; Show4.Max_Payload_kg = PayloadMax4; Show4.Acceptable = Useable4; Show4.Max_Disp_mm = Max_Disp4*1E3; Show4.Max_Stress_MPa = Max_Stress4*1E-6; Show4.Factor_of_Safety = FoS4; Show4.Thrust_to_Weight_Ratio = TWR; %Show4.Cost = cost4;
Show4.Total_Cost_Vol_USD = cost4*4;
Show4.Total_Cost_mass_USD = cost4g*4;

%To display the table created above. Also to make it easier for pdf viewers %to read the code.
disp('Triangle Arm / Model 1 Table');

Triangle Arm / Model 1 Table
disp(Show1);
Material | Mass_of_Arm_kg | Max_Payload_kg | Acceptable | Max_Disp_mm | Max_Stress_MPa | Factor_of_Safety | Thrust_to_Weight_Ratio | Total_Cost_Vol_USD | Total_Cost_mass_USD
_______________________________ | ______________ | ______________ | __________ | ___________ | ______________ | ________________ | ______________________ | __________________ | ___________________
"Carbon Fiber Composite (CFRP)" | 0.042778 | 0.82889 | "Yes" | 0.88702 | 24.564 | 24.426 | 2 | 2.8875 | 13.65
"Aluminum Alloy" | 0.072189 | 0.71125 | "Yes" | 0.89039 | 24.322 | 11.307 | 2 | 0.045118 | 5.7584
"Fiberglass Composite (GFRP)" | 0.050799 | 0.7968 | "No" | 2.4754 | 24.412 | 12.289 | 2 | 0.36094 | 8.1044
"PLA Plastic" | 0.033421 | 0.86632 | "No" | 17.814 | 24.866 | 2.4129 | 2 | 0.0045853 | 1.2441
"ABS Plastic" | 0.028073 | 0.88771 | "No" | 31.233 | 24.893 | 1.6069 | 2 | 0.0045853 | 1.045
"Wood (Birch)" | 0.016042 | 0.93583 | "No" | 6.2744 | 25.031 | 3.196 | 2 | 0.00085557 | 0.34124

disp('|');disp('|');disp('|'); %For spacing in the program

disp('Circle Arm / Model 2 Table');

Circle Arm / Model 2 Table
disp(Show2);
Material | Mass_of_Arm_kg | Max_Payload_kg | Acceptable | Max_Disp_mm | Max_Stress_MPa | Factor_of_Safety | Thrust_to_Weight_Ratio | Total_Cost_Vol_USD | Total_Cost_mass_USD
_______________________________ | ______________ | ______________ | __________ | ___________ | ______________ | ________________ | ______________________ | __________________ | ___________________
"Carbon Fiber Composite (CFRP)" | 0.024813 | 0.90075 | "Yes" | 0.21511 | 15.817 | 37.934 | 2 | 2.4322 | 4.3238
"Aluminum Alloy" | 0.041873 | 0.83251 | "Yes" | 0.21558 | 15.094 | 18.219 | 2 | 0.038003 | 1.8241
"Fiberglass Composite (GFRP)" | 0.029466 | 0.88214 | "Yes" | 0.60211 | 16.128 | 18.602 | 2 | 0.30402 | 2.5673
"PLA Plastic" | 0.019385 | 0.92246 | "No" | 4.2826 | 14.703 | 4.0808 | 2 | 0.0038622 | 0.3941
"ABS Plastic" | 0.016284 | 0.93486 | "No" | 7.5165 | 14.937 | 2.678 | 2 | 0.0038622 | 0.33104
"Wood (Birch)" | 0.009305 | 0.96278 | "No" | 1.5086 | 15 | 5.3332 | 2 | 0.00072064 | 0.1081

disp('|');disp('|');disp('|'); %For spacing in the program

disp('Beam Arm / Model 3 Table');

Beam Arm / Model 3 Table
disp(Show3);
Material | Mass_of_Arm_kg | Max_Payload_kg | Acceptable | Max_Disp_mm | Max_Stress_MPa | Factor_of_Safety | Thrust_to_Weight_Ratio | Total_Cost_Vol_USD | Total_Cost_mass_USD
_______________________________ | ______________ | ______________ | __________ | ___________ | ______________ | ________________ | ______________________ | __________________ | ___________________
"Carbon Fiber Composite (CFRP)" | 0.026745 | 0.89302 | "Yes" | 0.97521 | 56.122 | 10.691 | 2 | 2.592 | 4.608
"Aluminum Alloy" | 0.045133 | 0.81947 | "Yes" | 0.97876 | 55.185 | 4.9833 | 2 | 0.0405 | 1.944
"Fiberglass Composite (GFRP)" | 0.03176 | 0.87296 | "No" | 2.7284 | 56.411 | 5.3181 | 2 | 0.324 | 2.736
"PLA Plastic" | 0.020895 | 0.91642 | "No" | 19.455 | 55.193 | 1.0871 | 2 | 0.004116 | 0.42
"ABS Plastic" | 0.017552 | 0.92979 | "No" | 34.129 | 55.42 | 0.72176 | 2 | 0.004116 | 0.3528
"Wood (Birch)" | 0.010029 | 0.95988 | "No" | 6.8489 | 55.576 | 1.4395 | 2 | 0.000768 | 0.1152

disp('|');disp('|');disp('|'); %For spacing in the program

disp('Lattice Arm / Model 4 Table');

Lattice Arm / Model 4 Table
disp(Show4);
Material | Mass_of_Arm_kg | Max_Payload_kg | Acceptable | Max_Disp_mm | Max_Stress_MPa | Factor_of_Safety | Thrust_to_Weight_Ratio | Total_Cost_Vol_USD | Total_Cost_mass_USD
_______________________________ | ______________ | ______________ | __________ | ___________ | ______________ | ________________ | ______________________ | __________________ | ___________________
"Carbon Fiber Composite (CFRP)" | 0.091297 | 0.63481 | "Yes" | 0.057522 | 7.8082 | 76.842 | 2 | 14.855 | 26.409

"Aluminum Alloy" | 0.15406 | 0.38375 | "No" | 0.056408 | 7.5645 | 36.354 | 2 | 0.23211 | 11.141
"Fiberglass Composite (GFRP)" | 0.10841 | 0.56634 | "Yes" | 0.15999 | 7.7149 | 38.886 | 2 | 1.8569 | 15.68
"PLA Plastic" | 0.071326 | 0.7147 | "No" | 1.1542 | 7.9334 | 7.563 | 2 | 0.023589 | 2.4071
"ABS Plastic" | 0.059913 | 0.76035 | "No" | 2.0334 | 7.9782 | 5.0137 | 2 | 0.023589 | 2.0219
"Wood (Birch)" | 0.034236 | 0.86305 | "Yes" | 0.41169 | 8.088 | 9.8912 | 2 | 0.0044015 | 0.66022

%Section 8 (Visualizer)

%This is sectioned off to allow you to change results without having to
%repeat the whole code

%Since it is not properly reflected in the pdf this is the "Visualize PDE %Results" function

%The results have the following format:
% 'Model' + number + 'result' + material name
% This should be rather self explanatory to use %Lastly make sure Deformation is not ticked
% Data to visualize
meshData = Model_1_result_ASB.Mesh;
nodalData = Model_1_result_ASB.Displacement.Magnitude; deformationData = Model_1_result_ASB.Displacement;

% Create PDE result visualization
resultViz = pdeviz(meshData,abs(real(nodalData)), ... "DeformationData",deformationData, ... "DeformationScaleFactor",0.1921, ... "Title","Magnitude displacement", ... "ColorLimits",[0 0.03123]);


% Clear temporary variables
clearvars meshData nodalData deformationData

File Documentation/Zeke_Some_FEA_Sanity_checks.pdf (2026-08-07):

A user-defined function called “checkDroneArm” was written and used to analyze different designs. The results were checked with SolidWorks static simulation.

The function does both the thrust-to-weight and the FE analysis. The thrust-to-weight analysis gives the result of the max payload, which the challenge dictates should be above 0.5 kg. The function then uses MatLabs built in FEA.

SolidWorks simulation is used as a sanity check to verify the data from the MatLab FEA. The material compared is aluminum alloy.

Results for the Flat Arm Design:


Results for the Triangle Arm Design:


Max Stress Error: 0.774%
Max Displacement Error: 0.021%

Results for the Modified Triangle Arm Design:


Max Stress Error: 1.53%
Max Displacement Error: 0.102%

Results for beam arm V1:


Max Stress Error: 3.05%
Max Displacement Error: 0.3%

Results for Circle Arm V1

Max Stress Error: 12.3%
Max Displacement Error: 0.287%

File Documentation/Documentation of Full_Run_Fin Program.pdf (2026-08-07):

### Implementation details for Full_Run_Fin.mlx program

Section 1 Constants and Setup

- Loads droneArmMaterials.mat file
- Defines base drone specifications/assumptions from instructions: frame/electronics mass

(1.0 kg), quadcopter arms (4).

- Establishes operational criteria target Thrust-to-Weight Ratio (TWR = 2.0).
- Establishes and generates geometric, FEA, and mesh models

Section 2 Display models (For Devs)

- A section to view the models the program creates in order to check which faces to lock

and apply forces to

Section 3 Volume, Thrust to weight ratio, and cost calculations

- 2 volumes are calculated
- Vol# using the volume function for the drone arm

■ This is used for everything else besides costs. Allowing the program to

calculate the mass of the arms

- Vol#c using the maximum value in each axis to calculate the volume of a block

■ This is to give more accurate cost estimates as you would have to cut from

a block of material in order to make the arm.

■ Model 2’s is hand calced due to its stl file not being compatible with the

other method of extracting the maximum value for each axis

- 2 cost variables are calculated (This is due to the confusion regarding the cost variable

given by the droneArmMaterials.mat file. As the cost was $/m which was confusing as

the team was more use to things like $/m^3 or $/Kg)

- cost# uses the cost as ($/m) for calculations

■ This assumes that the units given were correct. So, that variable gets cubed

in order to calculate the cost of the arms

- cost#g uses the cost as ($/Kg) for calculations

■ This assumes that the units given were incorrect. So, that variable gets

multiplied by mass of the arm instead to calculate the cost of the arms

- For loop (Run calculations for vol, costs, max payload, and “Thrust to Weight Ratio”)
- Please refer to earlier cost and vol sections for specifics of the calcs
- The maximum possible payload is also calculated here.
- The “Thrust to Weight Ratio” is technically calculated here due to the fact that the

TWR is already locked to 2:1 or 2. So, if a payload is less than the maximum

possible, then the TWR is higher than 2:1 or 2.

Section 4 Applying and loading forces

- Applies and locks selected faces. (Reason for section 2)
- An equation is placed into the the surface traction being F/SA
- F = 9.07N refer to code for why (Open code or look at its pdf)

- SA is handcalced for each model. Values were tuned to SolidWorks as a reference

in FEA

Section 5 FEA Calculations

- Uses a switch case organize and fulfill FEA calculations
- Store FEA results in variable for later visualization

■ Formatted “model_#_(material name)”

- Finds max stress and displacement for each material for every arm.
- Calculates the factor of safety for each material for every arm.

Section 6 Arm Viability Check

- This section quickly checks whether the minimum requirements are met by the drone arm

with the selected material

- Max Payload weight >= 0.5Kg As specified by the problem documentation
- FoS >= 1.5 As suggested by the problem documentation
- Max displacement <= 0.001m or 1mm Value we set for ourselves
- This allows us to quickly check that conditions are met by the arm

Section 7 Setting up Tables

- This section creates 4 tables and the next non-numbered section displays said tables with

the model/arm it is referring to.

Section 8 Visualizer

- This section uses the “Visualize PDE Results” task to allow for easier viewing of the

model(s)/arm(s) stress and displacement visualizations.

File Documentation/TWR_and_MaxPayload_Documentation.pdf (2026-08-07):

### FEA Implementation Details for TWR_and_MaxPayload.m Program

1.1 Constants & Parameters Setup

- Defines base drone specifications: frame/electronics mass (1.0 kg), estimated base cost

($50.00), and quadcopter arms (4).

- Establishes physical constants (g = 9.81 m/s2 ) and operational criteria: thrust per motor

(9.81 N) and target Thrust-to-Weight Ratio (TWR = 2.0).

1.2 Geometry & Volume Calculation

- Reads arm geometry from STL files (CircleArm.STL / TriangleArm.STL).
- Computes exact volume using the Signed Tetrahedron Volume Method:
- Standardizes unit conversions between mm³ and m³ .

1.3 CSV Material Data Parsing

- Dynamically imports Materials.csv mapping:
- Material Name, Density (kg/m3 ), Cost per Unit Mass (USD/kg)
- Young’s Modulus (E), Poisson’s Ratio (ν), and Yield Strength (σy)

1.4 Mesh Generation & Boundary Conditions Setup

- Initializes a 3D static solid model using MATLAB’s PDE Toolbox (createpde).
- Generates a tetrahedral mesh with max element size Hmax = 0.002 m
- Visualizes geometry face IDs (pdegplot) and mesh topology (pdeplot3D).
- Calculates motor surface area (Face 10) to apply surface traction pressure:
- Fixes body mounting bolt faces (Face 5).

1.5 Multi-Material Loop & FEA Solver

1. Updates elasticity properties (E and ν) per row in the database.
2. Solves static equilibrium: Ku = F.
3. Extracts von Mises stress (σvm) and displacement magnitude (umag).
4. Evaluates Factor of Safety (FoS = σyield

/σvm,max).

5. Reports payload capacity and total system cost.

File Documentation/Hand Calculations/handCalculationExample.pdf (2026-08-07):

# Drone Arm Structural Analysis & Factor of Safety (FoS)

## 1 Geometric Parameters and Loading Conditions

The geometric parameters extracted from the CAD model and the operating conditions are as follows:

- Length between centers (L): 90 mm = 0.09 m
- Cross-sectional width (b): 30 mm = 0.03 m
- Cross-sectional thickness (h): 10 mm = 0.01 m
- Motor thrust mass (m): 1.0 kg
- Gravitational acceleration (g): 9.81 m/s²

## 2 Force and Bending Moment Calculations

### 2.1 Applied Thrust Force (F)

The upward force exerted by the motor at the tip of the arm is:

F = m · g = 1.0 kg × 9.81 m/s² = 9.81 N | (1)

### 2.2 Maximum Bending Moment (M)

Treating the arm as a cantilever beam fixed at the frame attachment point, the maximum bending moment occurs at the root:
M = F · L = 9.81 N × 0.09 m = 0.8829 N · m | (2)

## 3 Cross-Sectional Properties

For a rectangular cross-section of width b and thickness h:

### 3.1 Distance to Outer Fiber (c)

c =

h
2

=

0.01 m
2
= 0.005 m | (3)

### 3.2 Area Moment of Inertia (I)

I =

b · h

3
12

=

0.03 m × (0.01 m)³
12

= 2.50 × 10⁻⁹ m⁴
(4)

1

## 4 Maximum Bending Stress Calculations

Using the elastic flexure formula:

σmax =

M · c
I

(5)

Substituting the calculated values into the equation:

σmax =

0.8829 N · m × 0.005 m
2.50 × 10⁻⁹ m⁴
= 1, 765, 800 Pa ≈ 1.7658 MPa | (6)

Alternatively, using the direct cantilever rectangular formula:

σmax =

6 · F · L
b · h

2

=

6 × 9.81 N × 0.09 m
0.03 m × (0.01 m)²
= 1, 765, 800 Pa ≈ 1.7658 MPa | (7)

## 5 Factor of Safety (FoS) Analysis

The Factor of Safety is evaluated across various candidate materials using the material dataset properties:

FoS = σyield

σmax

(8)

Table 1: Material Properties and Factor of Safety Calculations (h = 10 mm)

Material | Yield Strength (σyield) | Bending Stress (σmax) | Factor of Safety (FoS)
Carbon Fiber Composite (CFRP) | 600 MPa | 1.7658 MPa | 339.79
Fiberglass Composite (GFRP) | 300 MPa | 1.7658 MPa | 169.89
Aluminum Alloy | 275 MPa | 1.7658 MPa | 155.74
Wood (Birch) | 80 MPa | 1.7658 MPa | 45.31
PLA Plastic | 60 MPa | 1.7658 MPa | 33.98
ABS Plastic | 40 MPa | 1.7658 MPa | 22.65

2

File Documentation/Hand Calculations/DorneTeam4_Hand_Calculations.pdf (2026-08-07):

## Drone Arm Hand Calculations

Beam Arm Design

This document presents the hand-calculated maximum payload, maximum displacement, maximum stress, factor of safety, and material cost for the beam arm design, evaluated using Aluminum Alloy.

## 1 Geometric and Material Parameters

- Length between centers (L): 183 mm = 0.183 m
- Cross-sectional width (b): 20 mm = 0.020 m
- Cross-sectional thickness (h): 6 mm = 0.006 m
- Arm volume (CAD, net of lattice cutouts): 16,707.72 mm³ = 1.670772 × 10⁻⁵ m³
- Material: Aluminum Alloy

– Density (ρ): 2700 kg/m³

– Young’s Modulus (E): 69 GPa = 6.9 × 10¹⁰ Pa

– Yield Strength (σyield): 275 MPa
– Cost per meter: $7.50 / m
- Motor thrust (per motor): 1.0 kg (treated as force-equivalent, per project convention)
- Motor + propeller mass: 0.075 kg
- Gravitational acceleration (g): 9.81 m/s²
- Number of motors: 4 Number of arms: 4
- Required thrust-to-weight ratio (TWR): 2.0
- Non-arm component mass: 1.0 kg

## 2 Maximum Payload Calculation

### 2.1 Arm Mass

marm = ρ · Varm = (2700 kg/m³
)(1.670772 × 10⁻⁵ m³
) = 0.045111 kg | (1)
marms,total = 4 · marm = 4(0.045111 kg) = 0.180443 kg | (2)

### 2.2 Total Thrust and Maximum Allowable Weight

Ttotal = nmotors · Tpermotor = (4)(1.0 kg) = 4 kg | (3)

Wmax =

Ttotal

TW Rrequired

=

4 kg
2.0
= 2 kg | (4)

### 2.3 Maximum Payload

Wpayload = Wmax − Wbody − marms,total | (5)
Wpayload = 2 kg − 1.0 kg − 0.180443 kg = 0.8196 kg | (6)

## 3 Maximum Displacement

Modeling the arm as a cantilever beam with a net tip load (thrust minus motor weight):

F = mthrust · g − mmotor · g = (1.0)(9.81) − (0.075)(9.81) = 9.074 N | (7)

I =

bh³

12

=

(0.020 m)(0.006 m)³

12

= 3.6 × 10⁻¹⁰ m⁴
(8)

δmax =

F L³

3EI

=

(9.074 N)(0.183 m)³
3(6.9 × 10¹⁰ Pa)(3.6 × 10⁻¹⁰ m⁴)

(9)

δmax ≈ 7.46 × 10⁻⁴ m ≈ 0.746 mm | (10)

## 4 Maximum Stress

M = F · L = (9.074 N)(0.183 m) = 1.6605 N · m | (11)

c =

h
2
= 0.003 m | (12)

σmax =

M c
I

=

(1.6605 N · m)(0.003 m)
3.6 × 10⁻¹⁰ m⁴
≈ 1.384 × 10⁷ Pa ≈ 13.84 MPa | (13)

## 5 Factor of Safety

F OS =

σyield

σmax

=

275 MPa
13.84 MPa
≈ 19.87 | (14)

## 6 Material Cost

Carm = Cper m · L = ($7.50/m)(0.183 m) = $1.3725 | (15)
Ctotal = 4 · Carm = 4($1.3725) = $5.49 | (16)

## 7 Summary of Results

Table 1: Hand-Calculated Results vs. MATLAB FEA – Beam Arm Design, Aluminum Alloy

Quantity | Hand Calculation | MATLAB FEA
Maximum Payload | 0.8196 kg | 0.8195 kg
Maximum Displacement | 0.746 mm | 0.9788 mm
Maximum Stress | 13.84 MPa | 55.1848 MPa
Factor of Safety | 19.87 | 4.89
Material Cost (4 arms) | $5.49 | –

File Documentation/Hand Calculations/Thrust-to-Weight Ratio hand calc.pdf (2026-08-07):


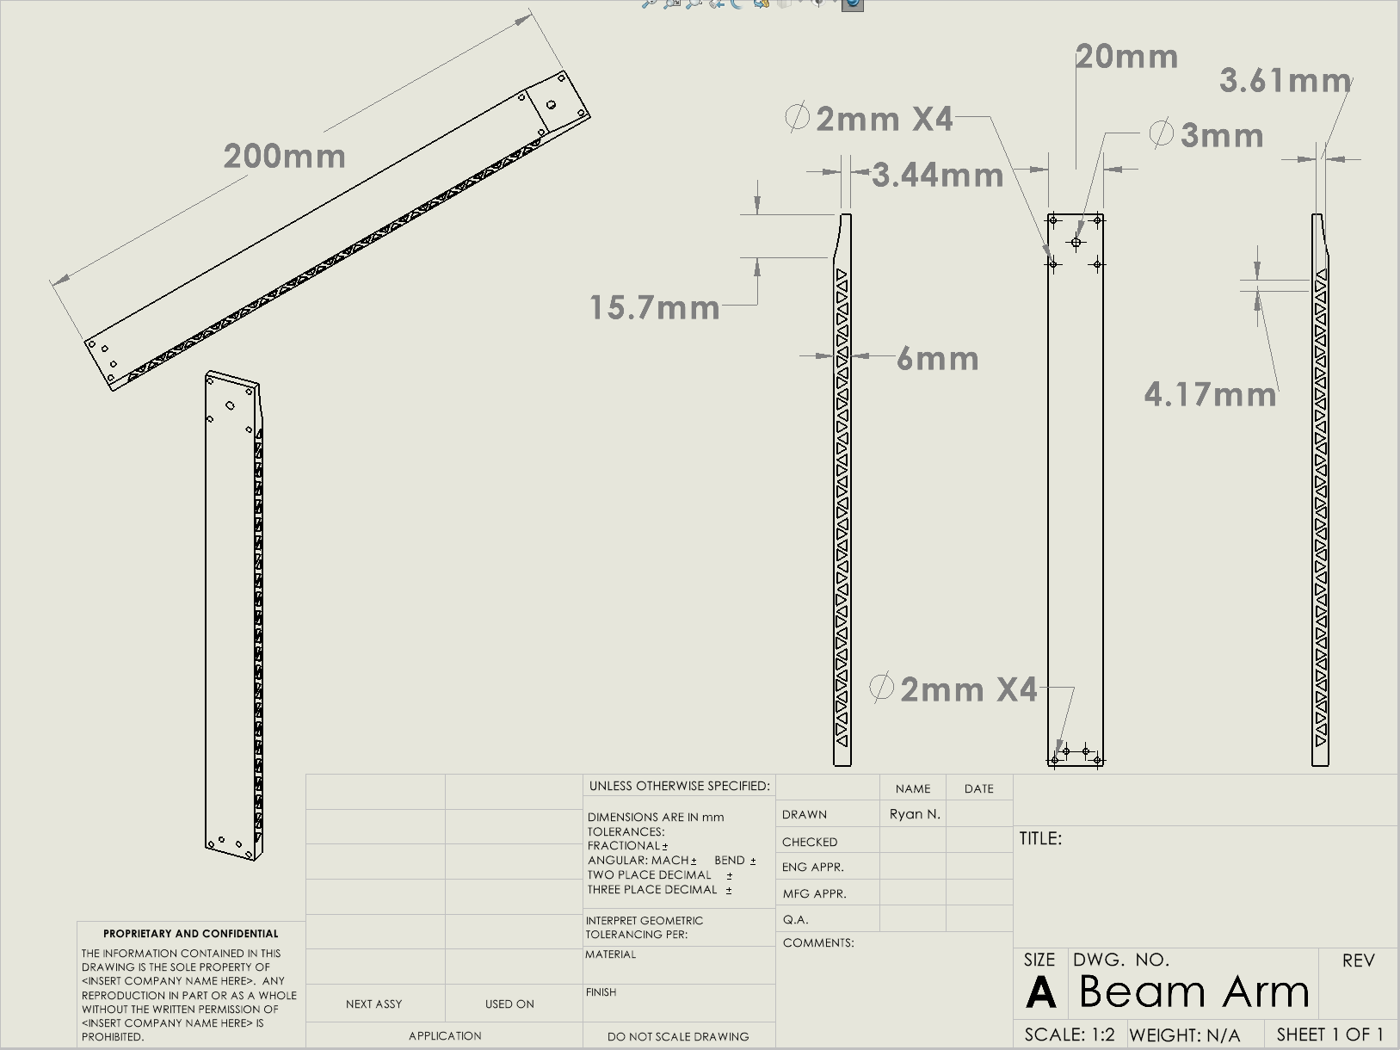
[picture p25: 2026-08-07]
Documentation/Beam Arm/SLDWORKS_A8Y2D8Zb0F.png

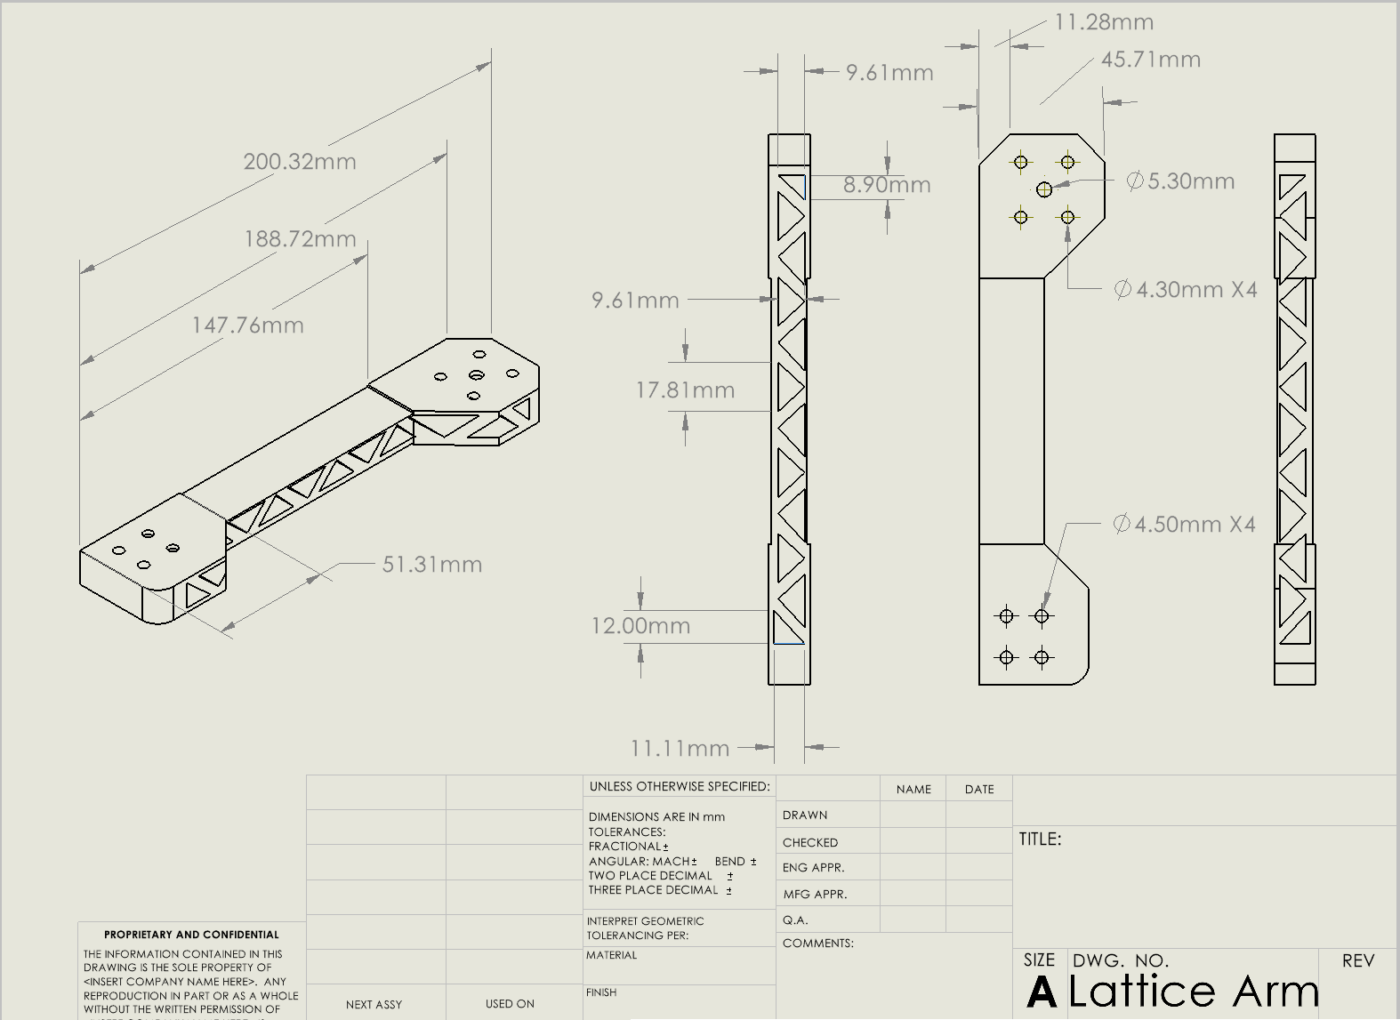
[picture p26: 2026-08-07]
Documentation/Lattice Arm/SLDWORKS_QFn3RDhtUH.png

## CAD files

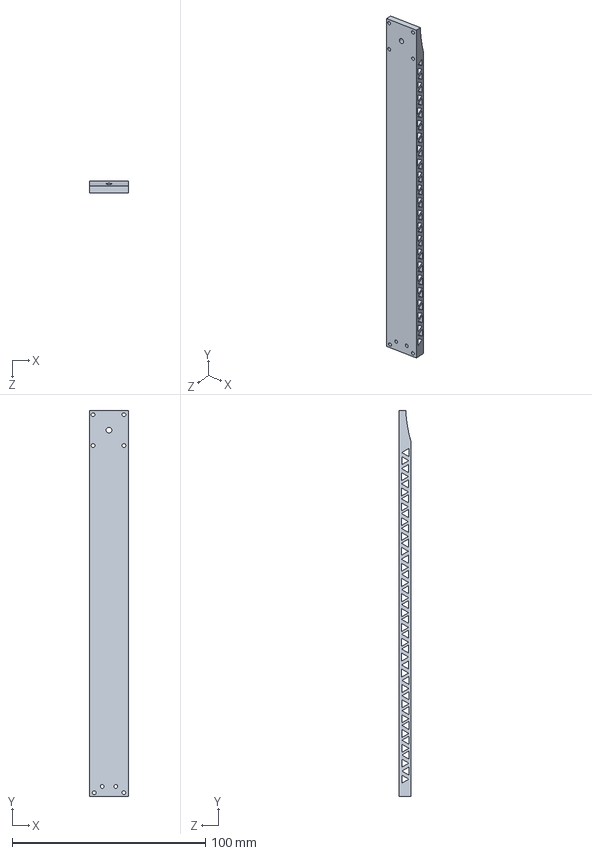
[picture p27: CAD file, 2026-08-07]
Documentation/Beam Arm/Beam_Arm.SLDPRT
20.0 x 200.0 x 6.00 mm

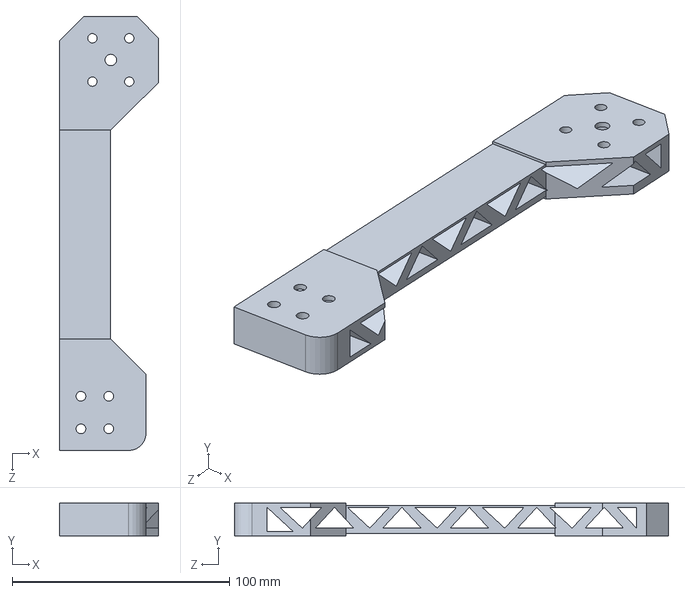
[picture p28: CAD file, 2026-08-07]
Documentation/Lattice Arm/PeterLatticeDroneArmV2.SLDPRT
45.8 x 15.0 x 200.0 mm

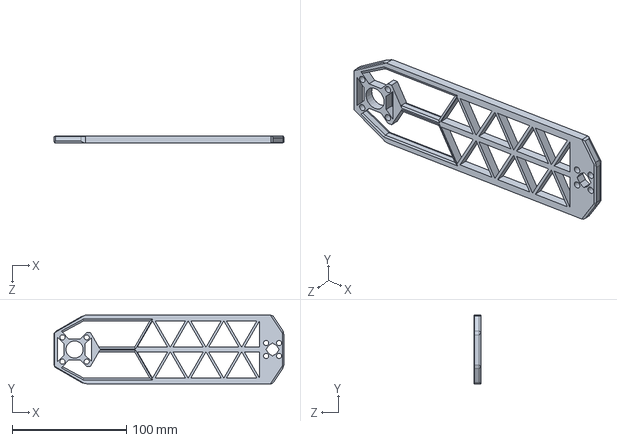
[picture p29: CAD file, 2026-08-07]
Documentation/Triangle Arm/TriangleArmMOD.SLDPRT
201.0 x 60.0 x 6.00 mm

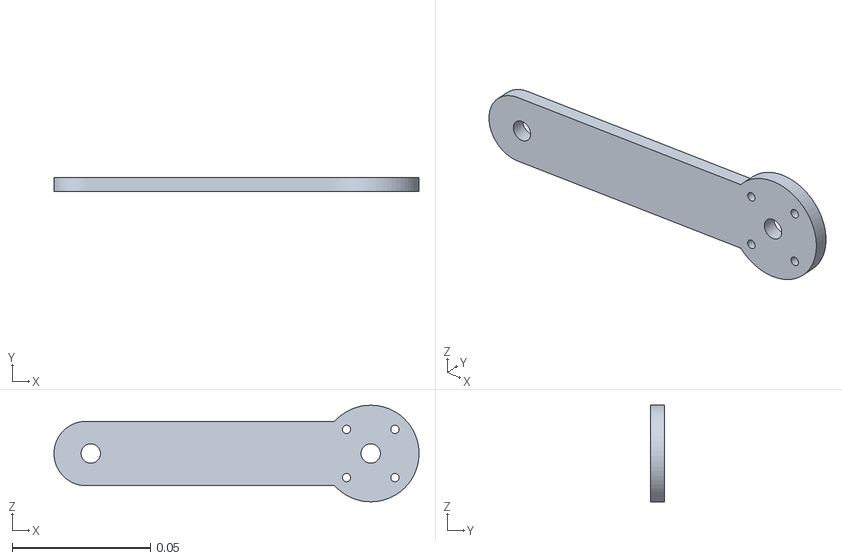
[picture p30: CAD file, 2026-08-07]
Circle_Arm.stl
0.132 x 0.005 x 0.035

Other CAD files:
Lattice_ArmV2.STL
Beam_Arm.STL
Triangle_ArmMOD.STL
Documentation/Beam Arm/beamdrawing.SLDDRW
Documentation/Lattice Arm/Lattice_ArmV2.SLDDRW
Documentation/Triangle Arm/TriangleArmMOD.SLDDRW

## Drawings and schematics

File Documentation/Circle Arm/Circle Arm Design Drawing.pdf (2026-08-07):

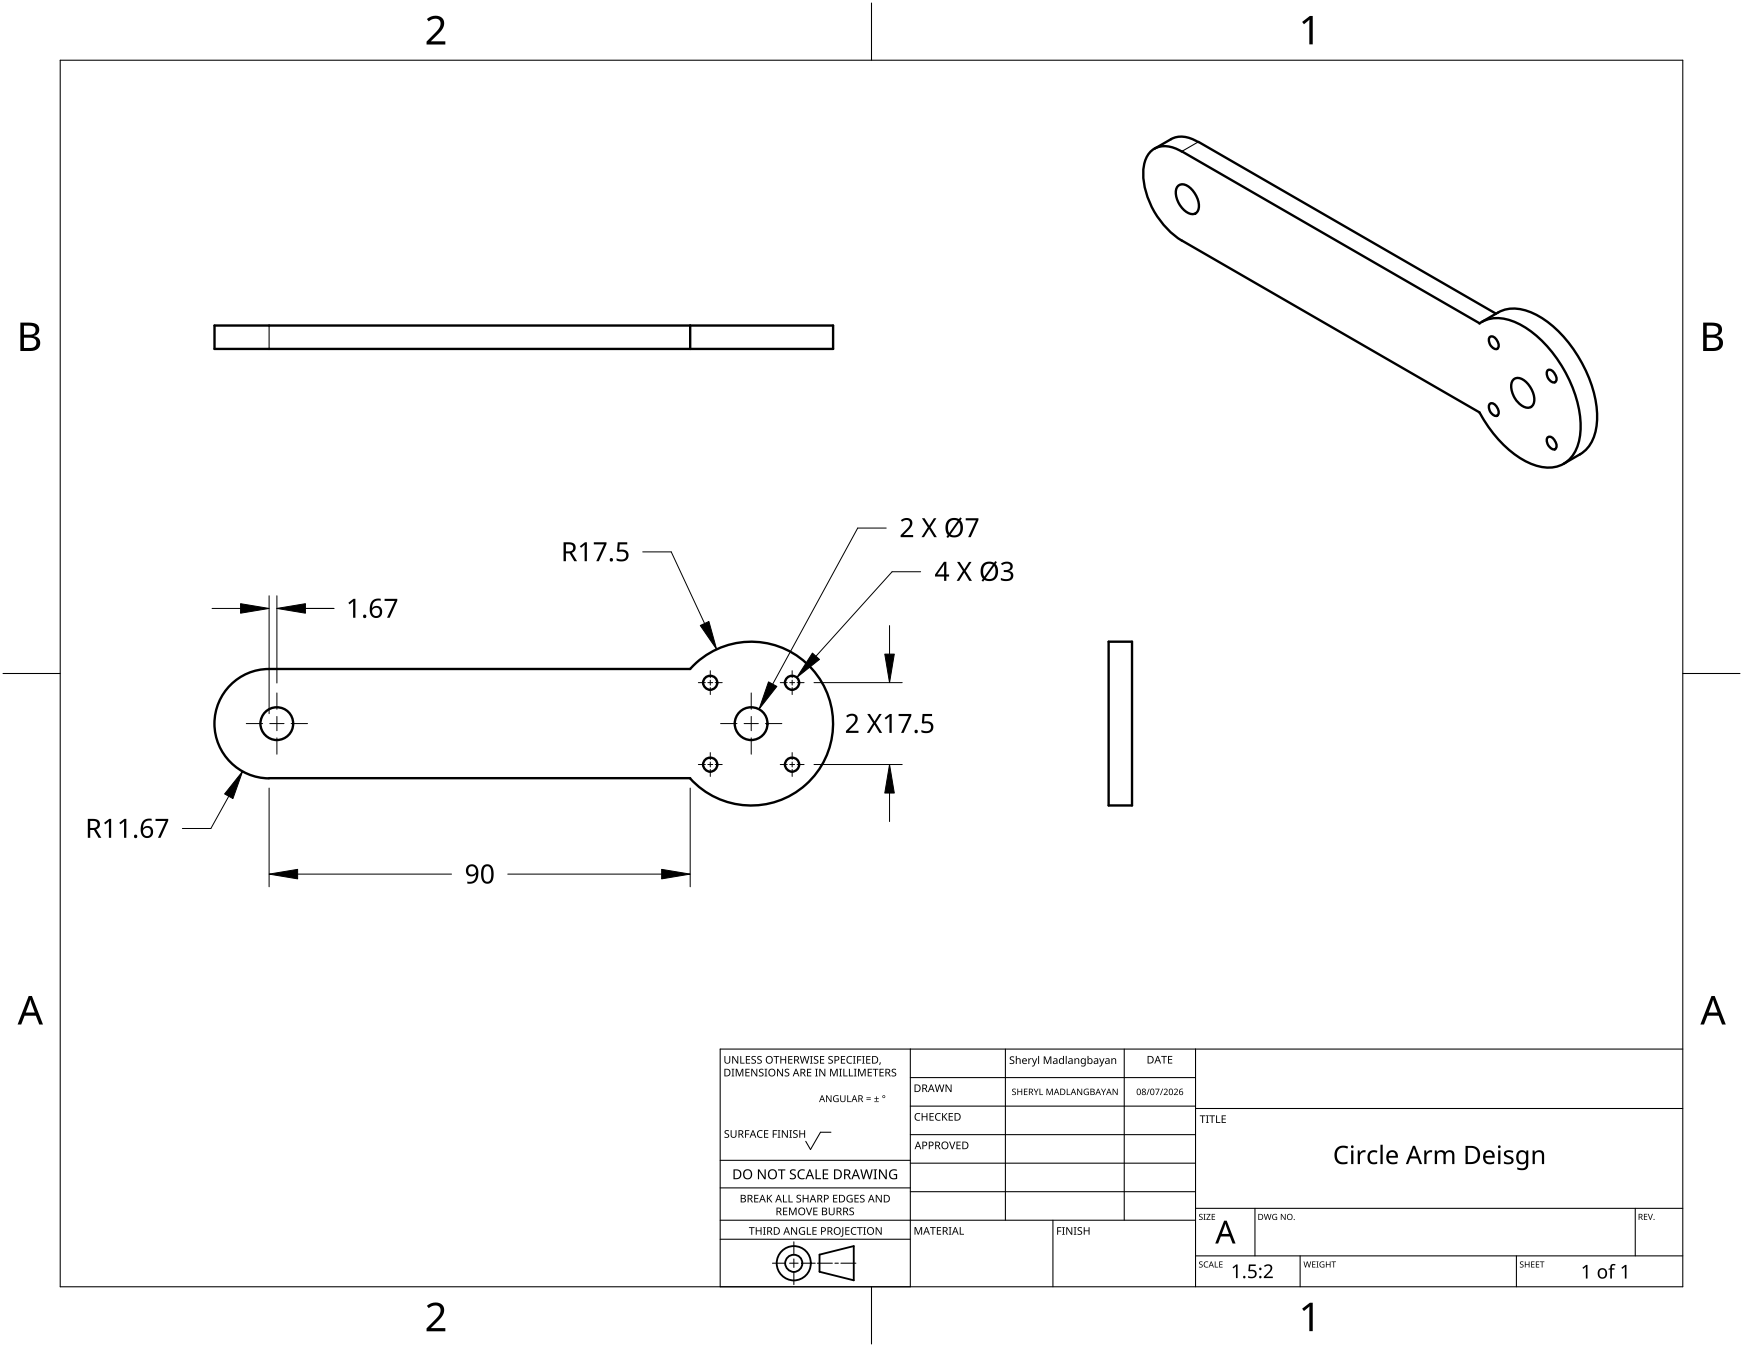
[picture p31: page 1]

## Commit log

2026-07-31 Uploaded main project files
    The main code, 2 drone arms and materials file
    [Nice.STL, TriangleArm.STL]
2026-08-07 Rename Documentation/Thrust-to-Weight Ratio hand calc.pdf to Documentation/Hand Calculations/Thrust-to-Weight Ratio hand calc.pdf
